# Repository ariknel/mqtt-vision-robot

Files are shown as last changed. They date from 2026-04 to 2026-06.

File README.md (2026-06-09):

# ESP32 MQTT Vision Robot

A line-following robot built around the **ESP32-DEVKITC V1**, featuring dual motor control via L298N, 3 IR line sensors, 3 ultrasonic distance sensors, and an LM2596S-ADJ buck converter powered by a custom 2S 18650 battery pack (8.4V fully charged). Fully controlled via a custom **Android MQTT app** with live telemetry, accelerometer tilt control, and WASD buttons.

All firmware is written in pure **ESP-IDF v5.x** (C). No Arduino framework. WiFi credentials are provisioned over BLE using NimBLE. Communication with the app uses MQTT over WiFi. The Android app runs an embedded MQTT broker — no cloud or external server needed.

---
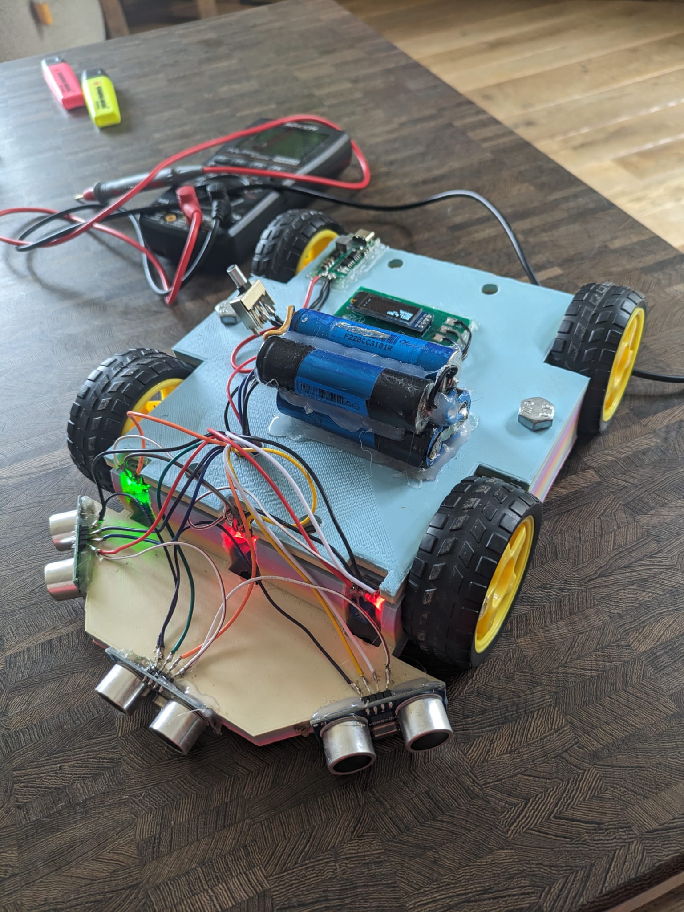
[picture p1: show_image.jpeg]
Show Image

## Table of Contents

- [Hardware Bill of Materials](#hardware-bill-of-materials)
- [Schematic](#schematic)
- [PCB Design Process](#pcb-design-process)
- [PCB Assembly & Testing](#pcb-assembly--testing)
- [Chassis — 3D Printed](#chassis--3d-printed)
- [Pinout Reference](#pinout-reference)
- [JST Connector Wiring](#jst-connector-wiring)
- [Power System](#power-system)
- [Motor Control](#motor-control)
- [Sensors](#sensors)
- [Firmware — Build & Flash](#firmware--build--flash)
- [Android App](#android-app)
- [First Run & WiFi Provisioning](#first-run--wifi-provisioning)
- [Control Modes](#control-modes)
- [Known Issues](#known-issues)
- [Build Log](#build-log)

---

## Hardware Bill of Materials

| Component | Part | Notes |
|---|---|---|
| MCU | ESP32-DEVKITC V1 | Dual-core, WiFi + Bluetooth |
| Motor Driver | L298N | Desoldered from L298N breakout module — correct Schottky freewheeling diodes reused |
| Buck Converter | LM2596S-ADJ | 8.4V → 5V, output set via RV1 trimpot. Rectifier diode: SS34 Schottky |
| Battery | Custom 2S 18650 pack (2× 18650 cells) | 8.4V fully charged, connected via JST J3 (2-pin) |
| Charger | Hailege 2S USB-C BMS Boost Charger | Charges to 8.4V via USB-C (5V input), overcharge and overcurrent protection |
| IR Sensors | Generic IR reflectance module × 3 | Digital output, 3.3V logic — connected via JST-B (10-pin) |
| Ultrasonic Sensors | HC-SR04 × 3 — **2021+ version** | ECHO outputs 3.3V logic — no voltage divider needed. Connected via JST-A (10-pin) |
| OLED Display | SSD1306 128×32 I2C | Mounted on a separate daughter PCB above the main board |
| Android App | Custom (Kotlin, Android Studio, API 29+) | Embedded MQTT broker + WASD / accelerometer control |

> The L298N was desoldered from a breakout module to reuse its Schottky freewheeling diodes, which are the correct type and are already soldered in the correct polarity.

> The HC-SR04 **must** be the 2021+ version, whose ECHO pin outputs 3.3V logic. Earlier versions output 5V on ECHO and require a voltage divider before connecting to ESP32 GPIO. Check the PCB revision marking or measure with a multimeter before connecting.

---

## Schematic

### Full Schematic — Rev 2

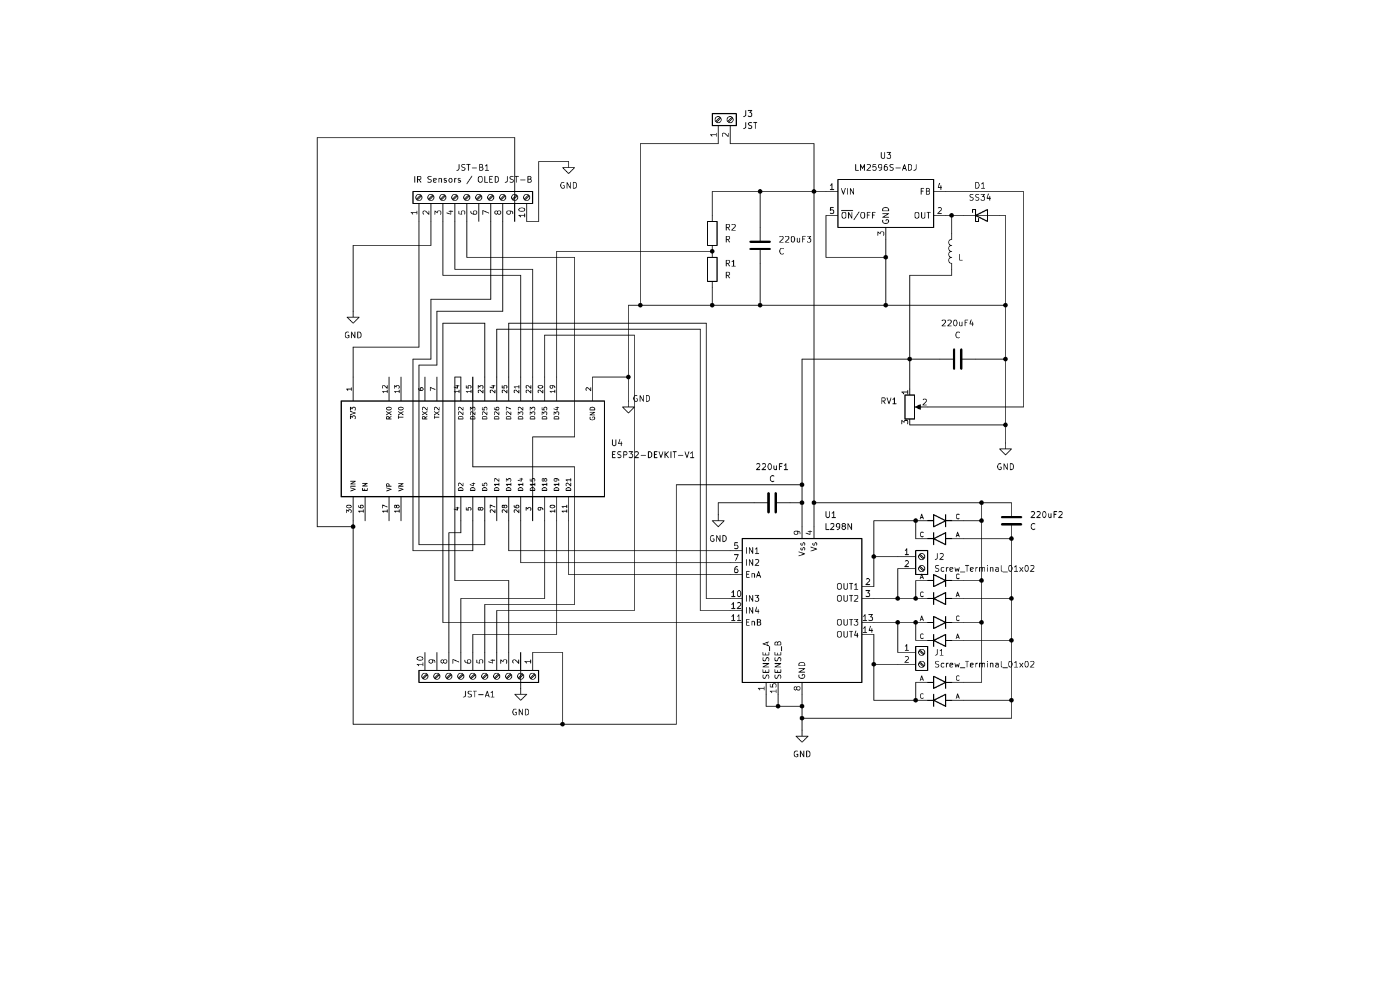
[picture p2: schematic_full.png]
Full Schematic


*ESP32-DEVKITC V1 + LM2596S-ADJ power section + L298N motor driver + JST-A ultrasonic connector + JST-B IR / OLED connector*

### LM2596S-ADJ — Buck Converter & Battery Monitor

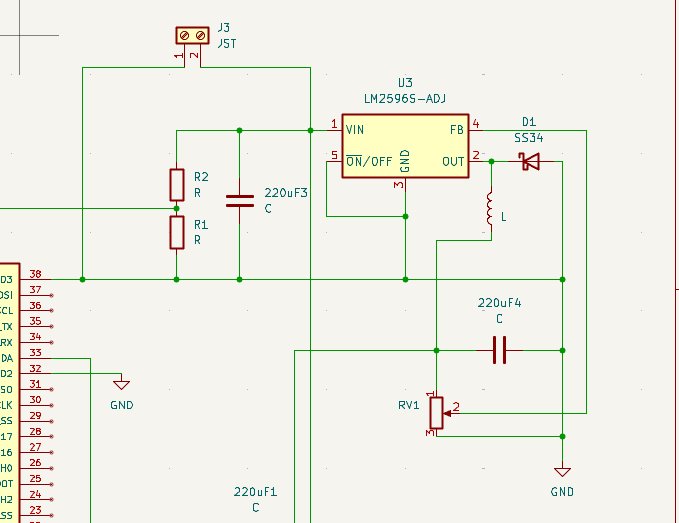
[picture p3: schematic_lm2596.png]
LM2596 Section


*8.4V input via J3 (2-pin JST). R1/R2 voltage divider (100 kΩ / 100 kΩ) feeds battery voltage to D34 for ADC monitoring. LM2596S-ADJ with SS34 Schottky diode D1, inductor L1, 220 µF input and output electrolytic capacitors, RV1 trimpot setting the 5V output via the FB pin.*

### L298N — Motor Driver

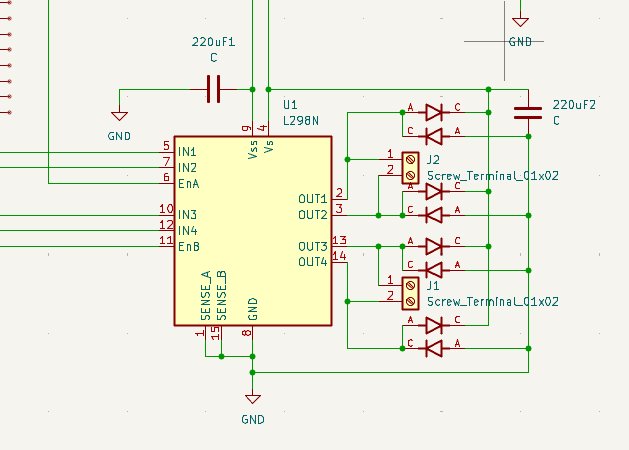
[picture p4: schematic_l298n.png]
L298N Section


*L298N dual H-bridge with 8 Schottky freewheeling diodes. Motor A: IN1 (D13), IN2 (D14), EnA (D21). Motor B: IN3 (D27), IN4 (D26), EnB (D25). Motor outputs routed to J1 and J2 screw terminals.*

---

## PCB Design Process

The PCB is designed in **KiCad**. Custom component footprints are in the `/footprints` folder of this repo.

### Step 1 — Schematic Capture

Built in KiCad's schematic editor. The following components were not in KiCad's default library and were imported manually:

- ESP32-DEVKITC V1
- LM2596S-ADJ
- L298N
- JST-A and JST-B connectors

### Step 2 — Component Placement

Components were placed manually, following these principles:

- **LM2596 power section** — tight left-to-right cluster: input capacitor → IC → inductor → Schottky diode → output capacitor. Keeps the switching current loop short to minimise EMI.
- **L298N** — centered on the board, freewheeling diodes grouped tightly around each output pair.
- **ESP32-DEVKITC V1** — centered, GPIO pins facing the connector side to reduce trace crossings.
- **JST-A and JST-B** — right edge of the board for clean external cable routing.
- **J1/J2 screw terminals** — bottom edge for easy motor wire access.
- **J3 power connector** — left edge, close to the LM2596 input.

### Step 3 — Design Rules

Configured via **File → Board Setup → Design Rules → Net Classes**:

| Netclass | Track Width | Clearance | Applied To |
|---|---|---|---|
| Default | 0.25 mm | 0.2 mm | All signal traces (GPIO, sensors, PWM) |
| Power | 1.0 mm | 0.8 mm | GND, 8.4V battery rail, 5V rail, motor output nets |

Power netclass assigned to: `GND`, `Net-(J3-Pin_2)` (8.4V battery), `Net-(JST-A1-Pin_1)` (5V rail), `Net-(J1-Pin_1/2)` (Motor A outputs), `Net-(J2-Pin_1/2)` (Motor B outputs).

### Step 4 — Board Outline

Rectangle drawn on the `Edge.Cuts` layer with ~5 mm clearance around all components using **Place → Rectangle**.

### Step 5 — Mounting Holes

4× `MountingHole_4.3x6.2mm_M4_Pad` placed at each corner for chassis standoff mounting. References set to H1–H4 (required for FreeRouter SES import compatibility).

### Step 6 — DRC (pre-routing)

Run via **Inspect → Design Rules Checker → Run DRC**:
- 3 silkscreen overlap warnings — fixed
- 0 footprint errors
- 69 unconnected pads (expected before routing)

### Step 7 — Auto-Routing with FreeRouter

1. **File → Export → Specctra DSN**
2. Open in FreeRouter, run the auto-router
3. **File → Import → Specctra Session (.ses)**
4. Review all traces manually and re-run DRC

Post-import DRC found 28 violations: decorative text placed on F.Cu (causing trace conflicts), IC pad spacing vs. power clearance rule violations, and 3 dangling track stubs. All fixed:
- Decorative text moved to F.Silkscreen layer
- Power clearance reduced from 0.8 mm to 0.5 mm to match IC footprint pad spacing
- 3 dangling stubs deleted

Final DRC: **0 errors, 2 warnings** (mounting hole library mismatch — ignorable).

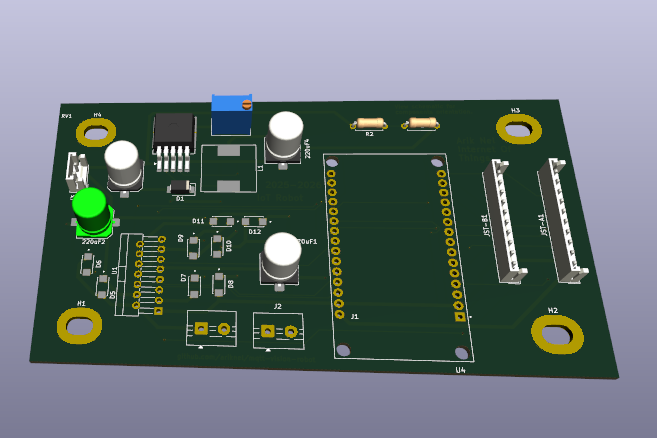
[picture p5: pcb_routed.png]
Routed PCB


*Fully routed 2-layer PCB. Red = F.Cu, blue = B.Cu. Thick traces = Power netclass (0.8 mm), thin = Default (0.25 mm).*

### Step 8 — Gerber Export & Manufacturing

> Board is production-ready. Final DRC: 0 errors.

1. **File → Plot** → Gerber format
2. Export all layers: F.Cu, B.Cu, F.Silkscreen, B.Silkscreen, F.Mask, B.Mask, Edge.Cuts + drill files
3. Submit to manufacturer — ordered as 2-layer, HASL finish, 5 copies

Gerber files are in the `/gerber` folder of this repo.

---

### OLED Display Board

A second small PCB was designed to mount a **SSD1306 128×32 I2C OLED** on top of the robot chassis. It sits above the main PCB, hides the main board from view, and connects back via the spare pins on JST-B.

The board contains no active components — just 4 solder test pads (H1–H4) for wire routing, a 4-pin JST connector (J5), and the OLED module footprint. Gerber files are in the `/gerber` folder alongside the main board gerbers.

**Why a separate board:**
- The main PCB had no remaining space for an OLED footprint
- Mounting on top of the chassis hides the main board for a cleaner look
- Can be detached and replaced independently from the main board

#### OLED Board Schematic

OLED Schematic

*J5 (4-pin JST) connects to H1 (GND), H2 (VCC), H3 (SCL), H4 (SDA). Short wires run from these pads to the OLED module pins.*

#### OLED Board PCB Layout

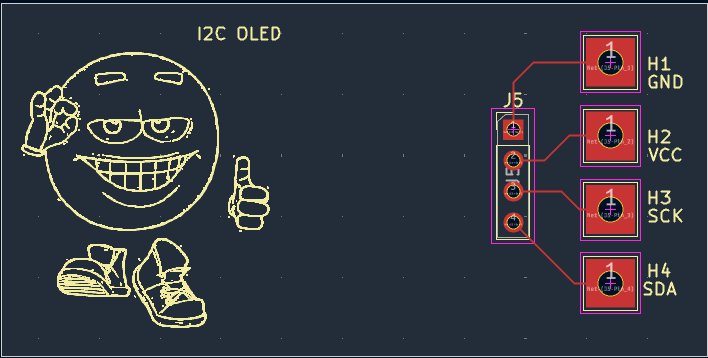
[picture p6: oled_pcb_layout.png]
OLED PCB Layout


*Minimal PCB — 4 test pad holes + JST connector. Sits on top of chassis above the main board.*

#### OLED Board 3D View

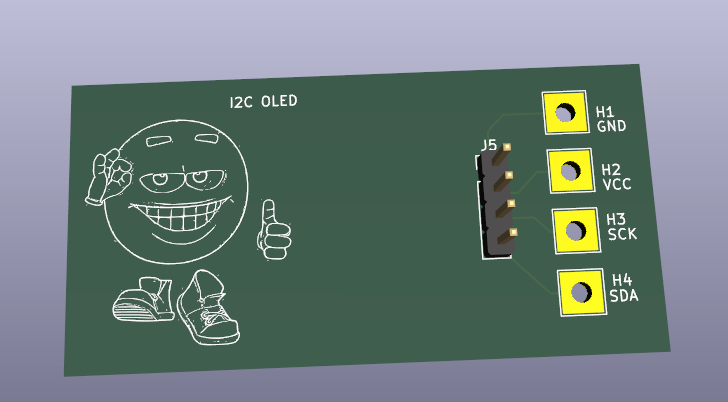
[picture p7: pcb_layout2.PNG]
OLED 3D View


#### OLED — JST-B Connection

The OLED board connects using the spare pins on JST-B (the IR sensor connector):

| JST-B Pin | Signal | OLED Board Pad | ESP32 GPIO |
|---|---|---|---|
| 6 | — spare — | — | — |
| 7 | SDA | H4 | D4 (Pin 5) |
| 8 | SCL | H3 | D5 (Pin 8) |
| 9 | VCC (5V) | H2 | — |
| 10 | GND | H1 | — |

> Verify your SSD1306 module accepts 5V on VCC. Most breakout modules have an onboard 3.3V LDO and accept 5V. Bare OLED modules without a regulator require 3.3V only.

> The ESP32's default I2C pins (D21/D22) are both used by the motor driver. I2C is remapped to D4 (SDA) and D5 (SCL) inside the ESP-IDF I2C driver configuration in `oled.c`.

#### OLED — What It Displays

| Line | Content |
|---|---|
| 1 | Battery voltage |
| 2 | MQTT connection status |
| 3 | Current mode (MANUAL / LINE FOLLOW) |
| 4 | Robot state (FOLLOWING / AVOIDING / RECOVERING) |

---

## PCB Assembly & Testing

**Do not solder all components at once.** Bring up the power circuit first and verify the output voltage before soldering the ESP32 or any sensors. This protects the ESP32 from overvoltage if the trimpot is set incorrectly from the factory.

### Step 1 — Inspect the Received PCBs

- Check for visible manufacturing defects: solder bridges, missing soldermask, lifted pads
- Hold the PCB up to light to check copper layer alignment
- Verify silkscreen labels match the schematic reference designators

### Step 2 — Solder the Buck Converter Circuit Only

Solder only the following components. Leave everything else unpopulated.

| Ref | Component |
|-----|---|
| J3 | 2-pin JST power input connector |
| U_LM2596 | LM2596S-ADJ IC |
| D1 | SS34 Schottky diode — stripe (band) = cathode |
| L1 | Inductor |
| C_in | 220 µF electrolytic input capacitor — stripe = GND (negative) |
| C_out | 220 µF electrolytic output capacitor — stripe = GND (negative) |
| RV1 | Trimpot |
| R1, R2 | 100 kΩ resistors (battery ADC voltage divider) |

Do **not** solder: ESP32, L298N, JST-A, JST-B, J1/J2 screw terminals, or any sensors yet.

### Step 3 — Set the Buck Converter Output to 5V
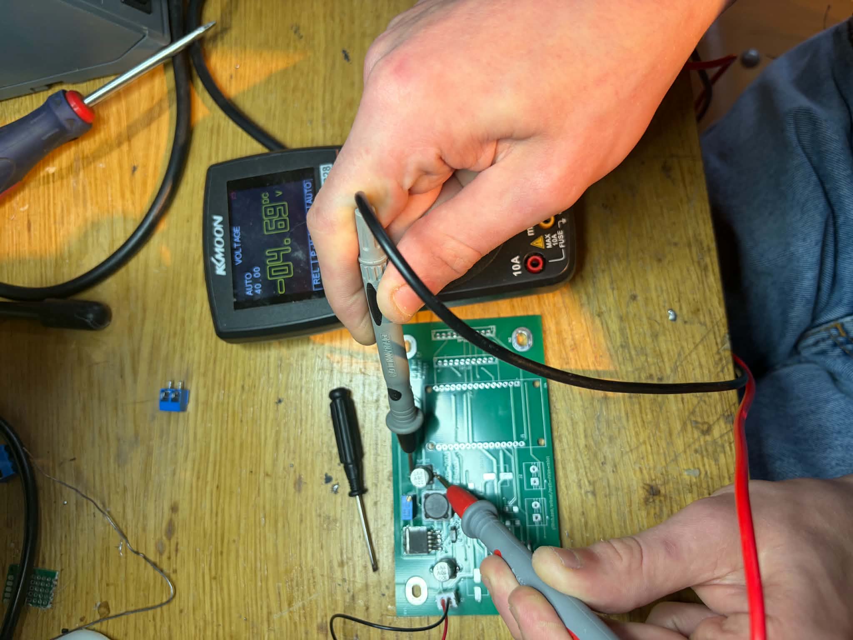
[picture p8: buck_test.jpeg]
Setting Buck to 5V

This is the most critical step. The LM2596S-ADJ output voltage is set by RV1. If left at the wrong position it may output the full battery voltage (up to 8.4V) to the 5V rail, which will destroy the ESP32.

1. Connect the 2S 18650 battery pack to J3 (Pin 1 = GND, Pin 2 = battery positive)
2. Set your multimeter to DC voltage
3. Place probes across the output capacitor C_out (or the 5V rail test points)
4. Slowly adjust RV1 until the meter reads **5.0V**
5. Confirm the reading is stable with no oscillation
6. Disconnect the battery

### Step 4 — Verify the Battery ADC Divider

> The firmware ADC saturates when the divider midpoint exceeds ~3.1V, which corresponds to a battery voltage of ~6.2V. This is a hardware limitation — the battery reading shows ~6.2V on a healthy 2S pack and only starts falling below 6.2V when the pack is nearly depleted. The app thresholds are set at 6.0V / 5.5V to account for this. This can be fixed in software with some calculations.

### Step 5 — Solder Remaining Components

Now that the 5V rail is confirmed correct and safe:

| Ref | Component |
|-----|---|
| U_L298N | L298N motor driver IC + all 8 Schottky freewheeling diodes |
| U_ESP32 | ESP32-DEVKITC V1 |
| JST-A | 10-pin connector (ultrasonic sensors) |
| JST-B | 10-pin connector (IR sensors + OLED) |
| J1, J2 | Screw terminals (motor A and motor B outputs) |

Solder the OLED daughter board separately — it is a standalone PCB.

### Step 6 — Power-On Verification

1. Connect the battery to J3
2. The ESP32 should boot — the onboard LED comes on
3. Connect the ESP32 to a PC via USB
4. Open a serial monitor at **115200 baud**
5. You should see BLE provisioning log output: `I (xxx) PROV: advertising as "IoT-Robot"`
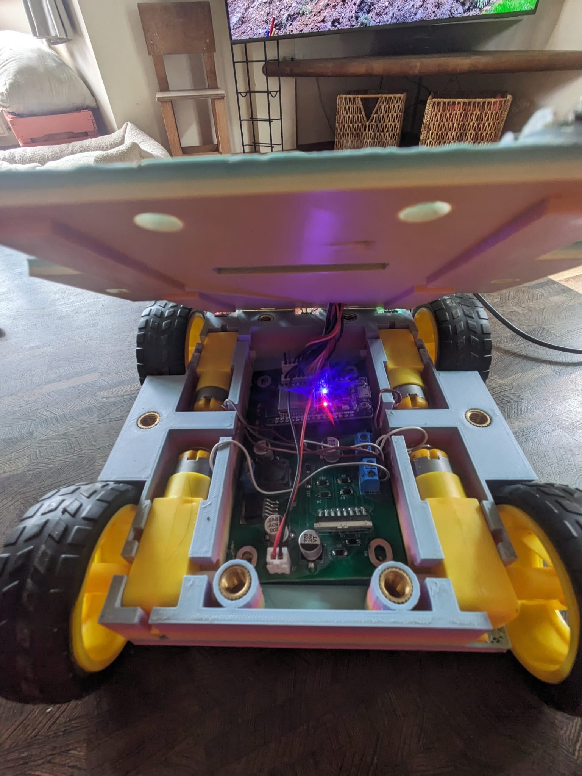
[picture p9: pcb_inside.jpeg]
PCB Mounted, still needs screwing down

If nothing appears on the serial monitor:
- Check battery polarity on J3
- Re-measure the 5V rail — must be 5V, not higher
- Verify ESP32 is seated correctly and all pins are soldered

### Step 7 — Connect and Test Sensors

Connect sensors one at a time and watch the serial output:

1. **IR sensors (JST-B)** — move a reflective object under each sensor; the digital output should toggle between 0 and 1
2. **Ultrasonic sensors (JST-A)** — wave your hand in front of each sensor; distances should appear in the telemetry log
3. **OLED board** — connect via JST-B spare pins 7–10; the display should show battery voltage and MQTT status after provisioning
4. **Motors (J1, J2)** — connect motors and verify direction in manual mode via the Android app

---

## Chassis — 3D Printed

The robot chassis is designed in **Autodesk Inventor** and 3D printed in PLA. The STEP file is in the root of this repo for reference and modification.

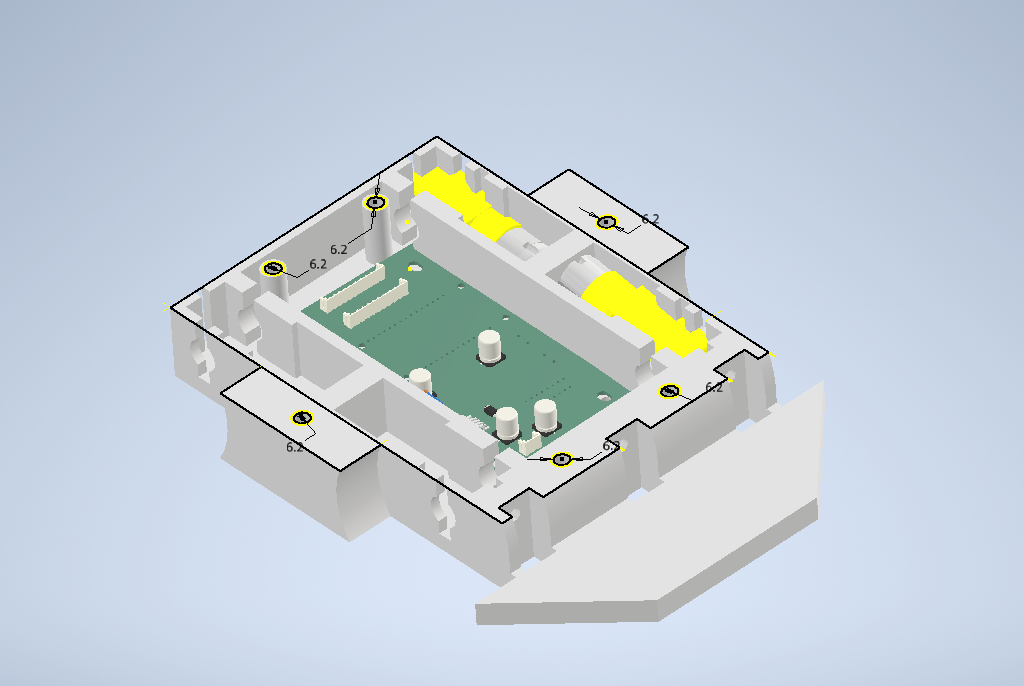
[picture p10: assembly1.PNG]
Chassis Assembly


*Autodesk Inventor assembly — PCB on standoffs, motor mounts, battery compartment, and sensor positions.*

**Design details:**
- IR sensors mount on the underside, facing down toward the ground for line detection
- HC-SR04 sensors mount on the front face in left, center, and right positions
- Motor mounts are integrated into the chassis base
- PCB sits on M4 standoffs matching the 4 corner mounting holes on the PCB
- Battery compartment is accessible from the bottom of the chassis

**Print settings used:** PLA, 0.2 mm layer height, 20% infill for non-structural sections, 50% infill for motor mounts and standoff pillars.

---

## Pinout Reference

### Motor Driver — L298N

| L298N Signal | ESP32 Label | ESP32 Pin | Type |
|---|---|---|---|
| IN1 | D13 | Pin 28 | Digital Output — Motor A direction |
| IN2 | D14 | Pin 26 | Digital Output — Motor A direction |
| EnA | D21 | Pin 11 | PWM Output — Motor A speed |
| IN3 | D27 | Pin 25 | Digital Output — Motor B direction |
| IN4 | D26 | Pin 24 | Digital Output — Motor B direction |
| EnB | D25 | Pin 23 | PWM Output — Motor B speed |

### Battery Monitor

| Function | ESP32 Label | ESP32 Pin | Notes |
|---|---|---|---|
| Battery ADC | D34 | Pin 19 | R1/R2 divider from J3 Pin 2. Input-only GPIO, ADC1 — WiFi safe |

### IR Line Sensors — JST-B (10-pin)

| Sensor | ESP32 Label | ESP32 Pin | Notes |
|---|---|---|---|
| IR Left | D32 | Pin 21 | ADC1 — WiFi/MQTT safe |
| IR Center | D33 | Pin 22 | ADC1 — WiFi/MQTT safe |
| IR Right | D15 | Pin 3 | Mild strapping pin — IR signal defaults LOW at boot, no conflict |

### Ultrasonic Sensors HC-SR04 (2021+) — JST-A (10-pin)

| Sensor | TRIG Label | TRIG Pin | ECHO Label | ECHO Pin | Notes |
|---|---|---|---|---|---|
| Left | D22 | Pin 14 | D35 | Pin 20 | ECHO input-only GPIO, ADC1 |
| Center | D23 | Pin 15 | D19 | Pin 10 | |
| Right | D18 | Pin 9 | D2 | Pin 4 | GPIO2 = onboard LED — LED flashes with echoes (cosmetic, sensor reads correctly) |

> HC-SR04 2021+: ECHO outputs 3.3V logic — direct connection to ESP32, no voltage divider needed.

### JST Power Connector — J3 (2-pin)

| Pin | Signal |
|-----|---|
| 1 | GND |
| 2 | Battery positive (8.4V fully charged) |

### Complete GPIO Map

| Label | ESP32 Pin | Function | Type |
|---|---|---|---|
| D2 | Pin 4 | ECHO Right (ultrasonic) | Input |
| D4 | Pin 5 | OLED SDA | I2C |
| D5 | Pin 8 | OLED SCL | I2C |
| D13 | Pin 28 | Motor A IN1 | Output |
| D14 | Pin 26 | Motor A IN2 | Output |
| D15 | Pin 3 | IR Right | Input |
| D18 | Pin 9 | TRIG Right (ultrasonic) | Output |
| D19 | Pin 10 | ECHO Center (ultrasonic) | Input |
| D21 | Pin 11 | EnA — Motor A speed | PWM Output |
| D22 | Pin 14 | TRIG Left (ultrasonic) | Output |
| D23 | Pin 15 | TRIG Center (ultrasonic) | Output |
| D25 | Pin 23 | EnB — Motor B speed | PWM Output |
| D26 | Pin 24 | Motor B IN4 | Output |
| D27 | Pin 25 | Motor B IN3 | Output |
| D32 | Pin 21 | IR Left | Input — ADC1 |
| D33 | Pin 22 | IR Center | Input — ADC1 |
| D34 | Pin 19 | Battery ADC | Input — ADC1, input-only GPIO |
| D35 | Pin 20 | ECHO Left (ultrasonic) | Input — ADC1, input-only GPIO |

---

## JST Connector Wiring

### JST-A — Ultrasonic Sensors (10-pin)

| Pin | Signal | ESP32 Label | ESP32 Pin |
|-----|---|---|---|
| 1 | 5V (shared VCC) | — | — |
| 2 | GND (shared) | — | GND |
| 3 | TRIG Left | D22 | Pin 14 |
| 4 | ECHO Left | D35 | Pin 20 |
| 5 | TRIG Center | D23 | Pin 15 |
| 6 | ECHO Center | D19 | Pin 10 |
| 7 | TRIG Right | D18 | Pin 9 |
| 8 | ECHO Right | D2 | Pin 4 |
| 9–10 | — spare — | — | — |

### JST-B — IR Line Sensors + OLED (10-pin)

| Pin | Signal | ESP32 Label | ESP32 Pin |
|-----|---|---|---|
| 1 | 3.3V (shared VCC) | — | — |
| 2 | GND (shared) | — | GND |
| 3 | IR Left | D32 | Pin 21 |
| 4 | IR Center | D33 | Pin 22 |
| 5 | IR Right | D15 | Pin 3 |
| 6 | — spare — | — | — |
| 7 | OLED SDA | D4 | Pin 5 |
| 8 | OLED SCL | D5 | Pin 8 |
| 9 | OLED VCC (5V) | — | — |
| 10 | OLED GND | — | GND |

VCC and GND are daisy-chained across all sensors within each connector group.

---

## Power System

```
[2S 18650 Battery Pack — 8.4V fully charged]
          │
       J3 (2-pin JST)  —  Pin 1: GND,  Pin 2: 8.4V
          │
          ├── R1 / R2 voltage divider (100 kΩ / 100 kΩ) ──── D34 Pin 19 (battery ADC)
          ├── 220 µF bulk input capacitor
          ├── L298N VS pin  (motors run from raw battery voltage)
          │
       LM2596S-ADJ  (D1: SS34 Schottky, RV1 trimpot → FB → 5V out)
       Output: 220 µF capacitor
          │
         5V rail ─────────── HC-SR04 VCC (JST-A Pin 1)
          │                  OLED VCC (JST-B Pin 9)
          │
       ESP32-DEV VIN ──── onboard LDO ──── 3.3V rail ──── IR sensor VCC (JST-B Pin 1)
```

The motors are powered directly from the battery voltage through the L298N VS pin — they operate at the full battery voltage, not the regulated 5V. The 5V rail powers only the ultrasonic sensors and OLED. The ESP32's onboard LDO produces the 3.3V rail for IR sensors and internal logic.

---

## Motor Control

The robot uses differential drive with the L298N dual H-bridge. Speed is controlled by PWM on the Enable pins (EnA/EnB). Direction is set by the IN1–IN4 logic inputs.

### H-Bridge Truth Table (per channel)

| IN_A | IN_B | Result |
|---|---|---|
| HIGH | LOW | Forward |
| LOW | HIGH | Reverse |
| LOW | LOW | Coast (free spin) |
| HIGH | HIGH | Brake |

### Differential Steering

| Action | Motor A (Left) | Motor B (Right) |
|---|---|---|
| Forward | Full speed | Full speed |
| Turn Left | Reduced speed | Full speed |
| Turn Right | Full speed | Reduced speed |
| Hard Left | Stop | Full speed |
| Hard Right | Full speed | Stop |
| Reverse | Full back | Full back |
| Spin Left | Full back | Full forward |
| Spin Right | Full forward | Full back |

> **Hardware note:** Motor A (left) has IN1 and IN2 wired backwards on the PCB. This is corrected in firmware inside the `drive()` function by inverting the polarity sent to PIN_IN1/PIN_IN2 for Motor A only. All higher-level motor commands (forward, reverse, turn, spin) are unaffected.

---

## Sensors

### IR Line Sensors (×3)

3 IR reflectance sensors mounted under the chassis for line detection. Digital output, 3.3V modules, connected via JST-B.

- All three GPIOs are on ADC1 — WiFi and MQTT remain active while reading
- No level shifting required (sensors output 3.3V logic)
- Firmware applies a 2-consecutive-read debounce before accepting a new state

**MQTT telemetry topic:** `robot/telemetry/ir`
```json
{"left": 0, "center": 1, "right": 0}
```

`1` = line detected (dark surface), `0` = no line (bright surface).

### Ultrasonic Sensors HC-SR04 2021+ (×3)

3 ultrasonic distance sensors for obstacle detection (left, center, right), connected via JST-A. Powered from the 5V rail.

ECHO connects directly to ESP32 GPIO — no voltage divider required (2021+ version outputs 3.3V logic).

Distance measurement uses an **interrupt-driven ISR** (`GPIO_INTR_ANYEDGE`). The rising edge records a timestamp in µs; the falling edge computes the distance as `pulse_us / 58`. This replaces the earlier polling approach, which missed short echo pulses at distances under ~170 cm.

**MQTT telemetry topic:** `robot/telemetry/ultrasonic`
```json
{"left": 24, "center": 8, "right": 31}
```

Values are in centimetres.

---

## Firmware — Build & Flash

The firmware is written in **C using ESP-IDF v5.4.1**. No Arduino framework, no PlatformIO.

### Project Structure

```
firmware/
├── CMakeLists.txt          — project root (IDF project)
├── sdkconfig.defaults      — NimBLE enabled, 8 KB main stack
└── main/
    ├── CMakeLists.txt      — lists all source files and dependencies
    ├── main.c              — app_main + 10 ms main loop
    ├── config.h            — all pin definitions and constants
    ├── provisioning.c/h    — BLE credential provisioning (NimBLE + NVS)
    ├── sensors.c/h         — IR, ultrasonic (ISR-driven), battery ADC
    ├── state_machine.c/h   — autonomy logic + motor control
    ├── mqtt.c/h            — WiFi STA + esp-mqtt client (event-driven)
    └── oled.c/h            — SSD1306 raw I2C driver + 5×7 font (no external lib)
```

### Firmware Architecture

```
app_main
  ├── provisioning_init()   — blocks on first boot (BLE); loads NVS on subsequent boots
  ├── sensors_init()        — configures GPIO, ISR handlers, ADC
  ├── state_machine_init()  — initialises LEDC channels and motor GPIOs
  ├── mqtt_init()           — blocks until WiFi + MQTT connected
  └── oled_init()           — I2C probe, skip gracefully if no OLED

Main loop (10 ms period)
  ├── sensors_read_ir()
  ├── sensors_read_ultrasonic()
  ├── sensors_read_battery()
  ├── state_machine_update()
  ├── every 100 ms → mqtt_publish_telemetry()
  └── every 500 ms → oled_update()
```

### Building on Windows (Docker + WSL2)

Build runs inside a Docker Dev Container. Flashing runs via WSL2 Ubuntu.

**One-time setup:**

1. Install [Docker Desktop](https://www.docker.com/products/docker-desktop)
2. Install WSL2 Ubuntu — PowerShell as Administrator:
   ```
   wsl --install -d Ubuntu
   ```
3. Install usbipd — PowerShell as Administrator:
   ```
   winget install usbipd
   ```
4. Inside Ubuntu terminal, install esptool:
   ```bash
   sudo apt update && sudo apt install pipx -y
   pipx install esptool
   pipx ensurepath
   source ~/.bashrc
   ```
5. Add yourself to the dialout group (then close and reopen the Ubuntu terminal):
   ```bash
   sudo usermod -aG dialout $USER
   ```

**Build (each session):**

1. Make sure Docker Desktop is running
2. Open the `mqttvision` folder in VS Code
3. `Ctrl+Shift+P` → **Dev Containers: Reopen in Container**
4. In the integrated terminal:
   ```bash
   cd /project/firmware
   idf.py build
   ```

**Flash (each session):**

1. Attach the ESP32 to WSL2 — PowerShell as Administrator:
   ```
   usbipd list
   usbipd bind --busid <BUSID>
   usbipd attach --wsl --busid <BUSID>
   ```
   The BUSID is listed next to "Silicon Labs CP210x" or "CH340". It may change if you use a different USB port.

2. Fix USB permissions if needed — Ubuntu terminal:
   ```bash
   sudo chmod 666 /dev/ttyUSB0
   ```

3. Flash — Ubuntu terminal:
   ```bash
   cd /mnt/c/Users/<you>/Desktop/mqttvision/firmware/build
   esptool.py --chip esp32 -p /dev/ttyUSB0 -b 460800 --before default_reset --after hard_reset write_flash @flash_args
   ```

4. Open the serial monitor:
   ```bash
   screen /dev/ttyUSB0 115200
   ```
   Exit with `Ctrl+A` then `K`.

**Erase flash** (when NVS needs clearing — e.g. stale WiFi credentials):
```bash
esptool.py --chip esp32 -p /dev/ttyUSB0 erase_flash
```
Then re-flash using Step 3 above.

### Building on Linux (Arch / Ubuntu native)

**One-time setup (Arch):**
```bash
sudo pacman -S git cmake ninja python python-pip python-pipx
sudo usermod -aG uucp $USER        # log out and back in after this
git clone --recursive https://github.com/espressif/esp-idf.git ~/esp/idf
cd ~/esp/idf && git checkout v5.4.1 && ./install.sh esp32
echo 'source ~/esp/idf/export.sh' >> ~/.bashrc && source ~/.bashrc
idf.py --version                   # should show ESP-IDF v5.4.1
```

**Build and flash:**
```bash
cd path/to/mqttvision/firmware
idf.py build
idf.py -p /dev/ttyUSB0 flash monitor
```

If permission is denied on `/dev/ttyUSB0`: `sudo chmod 666 /dev/ttyUSB0` (permanent: `sudo usermod -aG uucp $USER` then log out/in).

### Key Constants (config.h)

```c
/* Motor pins — L298N */
#define PIN_IN1   13    /* Motor A direction (wired backwards on PCB — corrected in drive()) */
#define PIN_IN2   14
#define PIN_ENA   21    /* Motor A speed (PWM) */
#define PIN_IN3   27    /* Motor B direction */
#define PIN_IN4   26
#define PIN_ENB   25    /* Motor B speed (PWM) */

/* IR sensors */
#define PIN_IR_LEFT    32
#define PIN_IR_CENTER  33
#define PIN_IR_RIGHT   15
#define IR_LINE_VALUE   0    /* GPIO level when sensor is on a dark line */
#define IR_DEBOUNCE_READS  2

/* Ultrasonic sensors */
#define PIN_TRIG_LEFT    22
#define PIN_ECHO_LEFT    35
#define PIN_TRIG_CENTER  23
#define PIN_ECHO_CENTER  19
#define PIN_TRIG_RIGHT   18
#define PIN_ECHO_RIGHT    2  /* GPIO2 = onboard LED — flashes with echoes (cosmetic only) */
#define ULTRA_TIMEOUT_US  25000  /* ~4 m max range, abort echo wait after this */

/* OLED I2C */
#define PIN_OLED_SDA   4
#define PIN_OLED_SCL   5
#define OLED_ADDRESS   0x3C

/* Battery ADC — GPIO34, ADC1_CH6 */
#define PIN_BATTERY      34
#define BATTERY_R1       100000.0f
#define BATTERY_R2       100000.0f

/* Speed — 8-bit PWM duty (0–255) */
#define SPEED_BASE        150   /* default speed, overridden by app slider */
#define SPEED_AVOID        90   /* cautious obstacle avoidance speed */
#define SPEED_CORRECTION   75   /* gentle correction turn speed */
#define SPEED_POST_CORR    80   /* forward speed when re-acquiring line */
#define SPEED_RAMP_STEP     2   /* PWM duty added per 10 ms tick while on-line */

/* Obstacle thresholds (cm) */
#define OBSTACLE_WARN_CM  20
#define OBSTACLE_STOP_CM  12

/* State machine timing */
#define RECOVERY_SWEEP_MS    2000
#define RECOVERY_SPIN_MS     5000
#define AVOID_MIN_MS          500
#define POST_AVOID_FWD_MS     600
#define RECOVERY_CREEP_MS     150

/* Loop intervals */
#define TELEMETRY_INTERVAL_MS  100
#define OLED_UPDATE_MS         500
#define MAIN_LOOP_MS            10

/* BLE provisioning window on every boot */
#define BLE_PROV_WINDOW_MS  30000
```

### Autonomous Mode — State Machine

The firmware runs a 3-state machine when in autonomous (line-follow) mode:

```
         ┌──────────────┐
    ┌───▶│  FOLLOWING   │◀────────────┐
    │    └──────┬───────┘             │
    │           │ obstacle < 20 cm    │ line found
    │           ▼                     │
    │    ┌──────────────┐             │
    │    │   AVOIDING   │             │
    │    └──────┬───────┘             │
    │           │ line lost (0,0,0)   │ line found
    │           ▼                     │
    │    ┌──────────────┐             │
    └────│  RECOVERING  │─────────────┘
         └──────────────┘
               │ no line after 5 s
               ▼
            STOP — await manual override via MQTT
```

**FOLLOWING** — normal line tracking using the IR truth table below. In the table, `1` = line detected (sensor on dark surface), `0` = not on line.

| IR Left | IR Center | IR Right | Action |
|---|---|---|---|
| 0 | 1 | 0 | Forward — centered on line |
| 0 | 1 | 1 | Curve right gently |
| 1 | 1 | 0 | Curve left gently |
| 0 | 0 | 1 | Turn right hard |
| 1 | 0 | 0 | Turn left hard |
| 1 | 1 | 1 | All sensors on line — forward |
| 1 | 0 | 1 | Junction or crossing — continue forward |
| 0 | 0 | 0 | Line lost — enter RECOVERING |

**AVOIDING** — triggered when any ultrasonic sensor reads < 20 cm. Robot curves around the obstacle using the left/right distance comparison to choose which side to go, keeping the outer IR sensor tracking the line edge for as long as possible.

**RECOVERING** — all IR sensors show 0 (line lost):
1. Remember which side sensor was last active
2. Slow down, turn that direction for up to 2 s
3. If line is found → return to FOLLOWING
4. If not found after 2 s → slow 360° spin scan
5. If still not found → stop and wait for manual override via MQTT

In **manual mode**, the state machine is bypassed entirely. MQTT move commands drive the motors directly.

---

## Android App

The Android app is built in **Kotlin** with **Jetpack Compose** (no XML layouts), targeting **API 29 (Android 10+)**. It embeds a full MQTT broker — no external server or cloud service needed.

### Architecture

```
[Android Phone]
      │
      ├── Moquette MQTT Broker (foreground service, port 1883)
      │         │
      │         └── Eclipse Paho MQTT Client (subscribes + publishes)
      │
      │   Local WiFi Network
      │
[ESP32-DEVKITC V1]
      │
      └── esp-mqtt client (connects to phone IP:1883)
            ├── Subscribes: robot/control/move, mode, speed
            └── Publishes:  robot/telemetry/#
```

The phone's local WiFi IP address acts as the broker address. The ESP32 learns this IP during BLE provisioning and connects on port 1883.

**Connection sequence:**
1. App launches → Moquette broker starts as a foreground service on port 1883
2. `MainActivity` waits for `MqttBrokerService.isRunning`, then Paho connects to `localhost:1883`
3. ESP32 boots → 30-second BLE window expires → WiFi connects → esp-mqtt connects to phone IP:1883
4. Handshake complete — telemetry flows in, controls work

### File Structure

```
MqttVisionRobot/app/src/main/java/com/ariknel/mqttvisionrobot/
├── MainActivity.kt           — entry point, broker lifecycle, screen routing
├── MqttBrokerService.kt      — Moquette broker as Android foreground service
├── MqttClientManager.kt      — Eclipse Paho client, publish helpers
├── BleProvisioningManager.kt — BLE scan, connect, write credentials, receive reply
├── RobotState.kt             — global Compose state (telemetry, connection, mode)
├── TelemetryParser.kt        — parses robot/telemetry/# JSON into RobotState
├── RobotControlScreen.kt     — main control UI (StatusBar, D-pad, speed, tilt, telemetry)
└── ProvisioningScreen.kt     — BLE provisioning form (auto-detects broker IP)
```

### MQTT Topics

| Topic | Direction | Payload |
|---|---|---|
| `robot/control/move` | App → ESP32 | `forward` / `back` / `left` / `right` / `stop` |
| `robot/control/speed` | App → ESP32 | PWM value `0`–`255` |
| `robot/control/mode` | App → ESP32 | `manual` or `line_follow` |
| `robot/telemetry/ir` | ESP32 → App | `{"left":0,"center":1,"right":0}` |
| `robot/telemetry/ultrasonic` | ESP32 → App | `{"left":24,"center":8,"right":31}` |
| `robot/telemetry/battery` | ESP32 → App | `8.21` (float string, volts) |
| `robot/telemetry/speed` | ESP32 → App | `{"a":180,"b":180}` |

All messages use **QoS 0** (fire-and-forget). At a 100 ms telemetry rate, a missed packet is irrelevant.

### Telemetry Dashboard

| Widget | Source | Notes |
|---|---|---|
| IR indicators | `robot/telemetry/ir` | 3 dot indicators — filled = line detected |
| Ultrasonic distances | `robot/telemetry/ultrasonic` | Live cm readouts Left / Center / Right |
| Battery voltage | `robot/telemetry/battery` | Colour-coded: green / amber / red |
| BROKER status | Internal | Live dot — Moquette running on phone |
| MQTT status | Internal | Live dot — ESP32 connected to broker |

### App UI

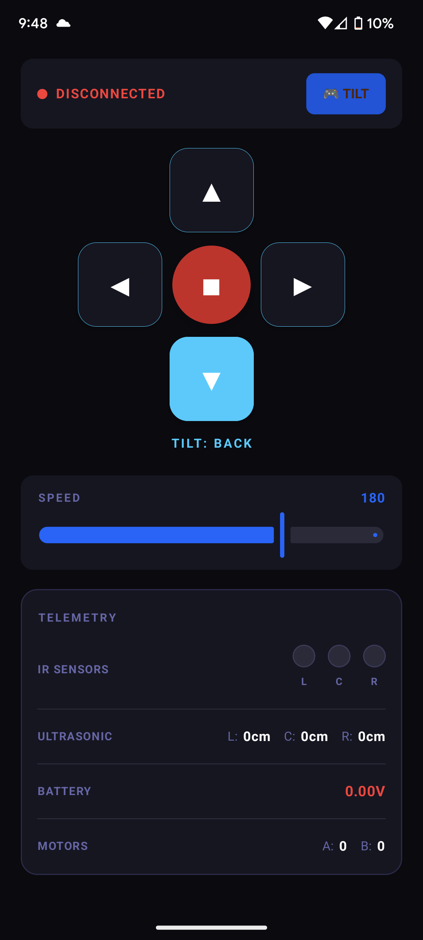
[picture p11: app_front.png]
App UI


### Dependencies

```kotlin
// MQTT Broker — Moquette embedded
implementation("io.moquette:moquette-broker:0.17")

// MQTT Client — Eclipse Paho
implementation("org.eclipse.paho:org.eclipse.paho.client.mqttv3:1.2.5")
implementation("org.eclipse.paho:org.eclipse.paho.android.service:1.1.1")

// Coroutines — async broker startup
implementation("org.jetbrains.kotlinx:kotlinx-coroutines-android:1.7.3")
```

---

## First Run & WiFi Provisioning

WiFi credentials and the MQTT broker IP are not hardcoded in firmware. On first boot, the ESP32 advertises over BLE and waits for provisioning.

**BLE service details:**

```
Device name:    IoT-Robot
Service UUID:   4fafc201-1fb5-459e-8fcc-c5c9c331914b
Characteristic: beb5483e-36e1-4688-b7f5-ea07361b26a8  (WRITE + NOTIFY)

Write payload:  {"ssid":"YourWiFi","password":"YourPass","broker":"192.168.x.x"}
Reply (notify): "OK"  — credentials saved, ESP32 restarts into WiFi mode
                "ERR" — malformed JSON, try again
```

**Boot behaviour:**

| Condition | What happens |
|---|---|
| No credentials in NVS (first boot) | BLE advertises indefinitely until credentials are received |
| Credentials present, normal boot | BLE advertises for 30 s (re-provision window), then stops and connects to WiFi |
| Boot immediately after provisioning | BLE skipped entirely (`fresh` NVS flag set), goes straight to WiFi |

**Provisioning steps:**

1. Power on the robot — the ESP32 advertises as `IoT-Robot`
2. Open the Android app and tap **BLE PROVISIONING**
3. The app auto-detects the broker IP from the phone's WiFi interface — only the WiFi SSID and password need to be typed in manually
4. Tap **PROVISION** — the app writes the JSON credentials over BLE
5. The ESP32 replies with "OK" and restarts
6. After restarting, the ESP32 connects to WiFi then to the MQTT broker running on the phone
7. The app status bar shows **BROKER OK** and **MQTT** connected

**Re-provisioning:** Power on the robot and connect via BLE within 30 seconds of boot.

**Full reset:** Erase NVS to force a first-boot state:
```bash
esptool.py --chip esp32 -p /dev/ttyUSB0 erase_flash
```
Then reflash the firmware.

---

## Control Modes

The app has two independent mode axes that can be combined freely.

### Drive Source — WASD or Tilt

Toggled by the **TILT/WASD** button. The accelerometer listener is registered and unregistered on each toggle to preserve battery.

**WASD mode (default):**

```
      [ W ]
 [ A ][ S ][ D ]
      [STP]
```

Hold a button to move; releasing it sends `stop`. The speed slider sets the PWM value (0–255).

**Tilt mode (accelerometer):**

| Tilt direction | Action |
|---|---|
| Forward | Move forward |
| Backward | Reverse |
| Left | Steer left |
| Right | Steer right |
| Flat | Stop |

Tilt speed is dynamic — a linear ramp from 80 to 255 as tilt angle increases. The speed slider updates in real time.

| Axis | Trigger threshold |
|---|---|
| Forward | `sensitivity − 0.6` (triggers slightly earlier for natural feel) |
| Left / Right | `sensitivity` |
| Reverse | `sensitivity + reverseGuard` |

A collapsible sensitivity panel (visible in tilt mode only) exposes two sliders:

| Slider | Effect |
|---|---|
| SENSITIVITY | Controls the trigger threshold for all axes |
| REVERSE GUARD | Extra tilt required to trigger reverse. Set to maximum (10) to disable reverse entirely |

### Autonomy — AUTO/MAN

Toggled by the **AUTO/MAN** button in the status bar.

- **MAN** — manual control via WASD or tilt. App publishes `manual` to `robot/control/mode`.
- **AUTO** — autonomous line-follow mode. App publishes `line_follow` to `robot/control/mode`. The control pad shows an "AUTO MODE" overlay and ignores all touch input. The ESP32 runs its state machine. The speed slider remains active — the firmware applies the current MQTT speed value in autonomous mode as well.

---

## Known Issues

| Priority | Issue | Status |
|---|---|---|
| Critical | LM2596 trimpot-only FB risk — if the RV1 wiper fails open, the full battery voltage reaches the 5V rail and destroys the ESP32. Fix: add R_upper 1 kΩ (VOUT→FB) + R_lower 1 kΩ (FB→GND) with RV1 in series with R_lower as a failsafe floor | Next PCB revision |
| Warning | Low-ESR capacitor recommended on LM2596 220 µF output capacitor | To verify |
| Info | ECHO Right on GPIO2 — the onboard LED flashes in sync with right ultrasonic echoes. GPIO2 cannot be changed without a PCB revision. The sensor reads correctly; the flashing is cosmetic only. | Accepted |
| OK | L298N Schottky freewheeling diodes — repurposed from module, correct type and polarity | Done |
| OK | LM2596 D1 = SS34 Schottky | Done |
| OK | HC-SR04 2021+ — ECHO direct to ESP32 GPIO, no voltage divider | Done |
| OK | All IR GPIOs on ADC1 — WiFi and MQTT remain active during sensor reads | Done |
| OK | No strapping pin conflicts in final pinout | Done |
| OK | D34 battery ADC — ADC1, input-only GPIO, WiFi safe | Done |
| OK | J3: Pin 1 = GND, Pin 2 = battery positive (8.4V) | Done |
| OK | ESP32-DEVKITC V1 has onboard 100 nF decoupling — no external cap needed | Done |
| OK | GPIO36/GPIO39 do not exist on DEVKITC V1 — replaced with D19 and D2 | Done |
| OK | BLE invisible after first provisioning — fixed with 30 s re-provision window + `fresh` NVS flag | Done |
| OK | BLE and WiFi radio conflict — NimBLE kept alive and competed with WiFi — fixed with `stop_nimble()` clean handoff before WiFi init | Done |
| OK | OLED I2C blocking serial (720 ms/update) when no OLED connected — fixed with `i2c_master_probe()` presence check at init | Done |
| OK | Android broker IP returning cellular IP on dual-SIM phones — fixed by filtering `allNetworks` for WiFi transport only | Done |
| OK | Moquette failing silently (`catch Exception` missed Netty errors) — fixed with `catch Throwable` + `data_path = filesDir.absolutePath` | Done |
| OK | ESP32 ignoring the speed slider — added `robot/control/speed` subscription + `state_machine_set_speed()` | Done |
| OK | Motor A (left) IN1/IN2 wired backwards on PCB — corrected in `drive()` by inverting PIN_IN1/PIN_IN2 polarity for Motor A only | Done |
| OK | WASD fast-tap locks direction (`collectIsPressedAsState` missed short presses) — replaced with `pointerInput` + `awaitEachGesture` / `awaitFirstDown` / `waitForUpOrCancellation` | Done |
| OK | No AUTO/MAN mode toggle in app — AUTO/MAN button added to StatusBar; sends `line_follow` / `manual` to `robot/control/mode` | Done |
| OK | Autonomous speed ignored MQTT speed commands — all `m_*` motor helpers now scale from `s_speed` instead of hardcoded constants | Done |
| OK | Battery reading ~13V (wrong VREF, no calibration) — replaced with `adc_cali_line_fitting` + 8-sample averaging; fallback uses correct 3100 mV full-scale | Done |
| Warning | Battery divider 2×100 kΩ (1:1) saturates ADC above ~6.2V — a healthy 2S pack reads fixed at ~6.2V; only drops below when the pack is nearly dead. App thresholds set to 6.0V / 5.5V. | Hardware limitation — acceptable |
| OK | OLED I2C timeouts at 400 kHz — SCL reduced to 100 kHz, timeout extended to 50 ms; error counter: bus reset on 5th consecutive fail, auto-disable on 20th | Done |
| OK | Ultrasonic always reading 400 cm (polling loop missed short echo pulses < ~170 cm) — replaced with interrupt-driven ISR (`GPIO_INTR_ANYEDGE`) recording µs-precision timestamps | Done |

---

## Build Log

| Date | Entry |
|---|---|
| 24 Apr 2026 | Rev 1 schematic complete. ESP32 + LM2596S-ADJ + L298N architecture established. |
| 24 Apr 2026 | EnA strapping conflict on D12 found and corrected → D21. |
| 24 Apr 2026 | R1/R2 confirmed as battery ADC voltage divider, not LM2596 feedback resistors. |
| 24 Apr 2026 | L298N repurposed from breakout module — correct Schottky freewheeling diodes confirmed. |
| 24 Apr 2026 | Android MQTT app architecture defined — embedded broker, dual control modes, telemetry dashboard. |
| 25 Apr 2026 | JST-A (ultrasonic) and JST-B (IR) connectors added to schematic and PCB. |
| 25 Apr 2026 | Full GPIO conflict check — all pins verified clean. |
| 25 Apr 2026 | HC-SR04 confirmed 2021+ version — voltage dividers removed from design. |
| 25 Apr 2026 | Final GPIO assignments locked in. LM2596 D1 = SS34 Schottky confirmed. |
| 25 Apr 2026 | Schematic Rev 2 exported — JST-A and JST-B fully connected. |
| 27 Apr 2026 | PCB design completed. L298N diode orientation corrected — all 8 diodes consistent anode/cathode orientation. |
| 27 Apr 2026 | Incorrect ESP32 footprint (WROOM-32D) found and replaced → ESP32-DEV DEVKITC V1. Custom footprints uploaded to `/footprints`. |
| 27 Apr 2026 | All pin numbers updated to DEVKITC V1 layout. GPIO36/39 replaced with D19/D2. 16 GPIOs used, 0 conflicts, 9 spare. |
| 27 Apr 2026 | DRC run — 3 silkscreen warnings fixed. 0 footprint errors. |
| 27 Apr 2026 | JST connector found placed upside down — fixed by flipping in KiCad PCB editor. |
| 27 Apr 2026 | Mounting hole references changed from numeric (1,2,3,4) to H1–H4 to resolve FreeRouter SES import error. |
| 27 Apr 2026 | FreeRouter auto-routing completed with 0 unrouted connections. Power netclass: 0.8 mm trace, 0.7 mm clearance. Signal: 0.25 mm trace, 0.2 mm clearance. |
| 27 Apr 2026 | SES imported into KiCad. All 28 DRC violations fixed: decorative text moved to F.Silkscreen, power clearance reduced to 0.5 mm to match IC pad spacing, 3 dangling stubs deleted. |
| 27 Apr 2026 | PCB routing complete. Final DRC: 0 errors, 2 warnings (mounting hole library mismatch — ignorable). Board is production-ready. |
| 27 Apr 2026 | GitHub URL added to PCB silkscreen. Gerber files exported and uploaded to `/gerber`. |
| 27 Apr 2026 | Power source confirmed: custom 2S 18650 pack (8.4V fully charged), charged via Hailege 2S USB-C BMS boost charger. |
| 27 Apr 2026 | Android app built and running. WASD + tilt mode, telemetry panel, speed slider. Dynamic tilt speed ramp, reverse guard, collapsible sensitivity panel added. |
| 27 Apr 2026 | Chassis design started in Autodesk Inventor. STEP file uploaded to repo. |
| 29 Apr 2026 | OLED board designed in KiCad — 128×32 SSD1306 I2C, separate PCB for mounting on chassis top. Connects via JST-B spare pins 7–10. ECHO Right moved D4 → D2; D4 and D5 assigned to OLED SDA/SCL. Gerbers added. |
| 29 Apr 2026 | Chassis assembly rendered in Autodesk Inventor. Assembly image added to repo. |
| 30 Apr 2026 | Final gerber review — main PCB and OLED board gerbers cross-checked. All layers verified (F.Cu, B.Cu, F.Silkscreen, B.Silkscreen, F.Mask, B.Mask, Edge.Cuts, drill). |
| 2 May 2026 | Main PCB and OLED board ordered from JLCPCB. 2-layer, HASL finish, 5 copies each. |
| 3 May 2026 | Firmware development started. All module headers defined: provisioning, sensors, state_machine, mqtt, oled. |
| 4 May 2026 | Chassis design finalised — mounting hole positions and motor mount spacing verified. |
| 4 May 2026 | sensors.c: IR reading with 2-read debounce, round-robin ultrasonic (non-blocking), battery ADC with voltage divider formula. state_machine.c skeleton. |
| 6 May 2026 | state_machine.c — 3-state machine (FOLLOWING / AVOIDING / RECOVERING) implemented. mqtt.c — WiFi connect, esp-mqtt event-driven client, telemetry JSON at 100 ms. |
| 7 May 2026 | provisioning.c — NimBLE GATT service, JSON credentials written to NVS. oled.c — SSD1306 raw driver, 5×7 font, battery + MQTT + mode/state display. |
| 8 May 2026 | main.c complete — all modules wired together and compiling. Chassis sent to 3D printer (PLA, 0.2 mm layer height, 20 % / 50 % infill). |
| 10 May 2026 | CLAUDE.md created. README audited and updated: OLED features, BLE provisioning section, constants. |
| 10 May 2026 | Auto-changelog hook configured in Claude Code — build log updated automatically after each code change. |
| 11 May 2026 | Full migration from Arduino to ESP-IDF v5.x. All .cpp files replaced with .c. Arduino framework, PubSubClient, ArduinoJson, and Adafruit SSD1306 removed. NimBLE replaces Bluedroid. esp-mqtt replaces PubSubClient. adc_oneshot API replaces legacy ADC. LEDC replaces ledcSetup/ledcWrite. I2C legacy driver with raw SSD1306 init sequence and 5×7 font inline. Motors merged into state_machine.c. Provisioning char upgraded to WRITE+NOTIFY. |
| 12 May 2026 | Android provisioning screen: broker IP auto-detected from phone's WiFi interface. WiFi network filter prevents cellular IP being selected on dual-SIM phones. Broker field is read-only with AUTO-DETECTED badge. |
| 12 May 2026 | HOW_TO_BUILD_AND_FLASH.txt updated: Ubuntu terminal open instructions, erase flash step corrected. |
| 13 May 2026 | BLE redesigned: 30 s re-provision window on every boot. `NVS_KEY_FRESH` flag skips BLE on boot immediately after provisioning. `stop_nimble()` (adv stop → port stop → 300 ms → deinit) called before WiFi init for clean radio handoff. |
| 13 May 2026 | OLED graceful no-hardware handling: `i2c_master_probe()` presence check at init. `s_present` guard in `oled_update()` eliminates 720 ms I2C blocking per loop when no OLED is connected. |
| 14 May 2026 | Android manifest: `FOREGROUND_SERVICE_CONNECTED_DEVICE` permission added — required for Android 14+ foreground service. |
| 14 May 2026 | Android `MainActivity`: fixed 1500 ms startup delay replaced with `MqttBrokerService.isRunning` poll — Paho connects only after Moquette has bound to port 1883. |
| 15 May 2026 | Moquette: `catch (Exception)` → `catch (Throwable)` so Netty startup errors surface in logcat. Root cause: H2 store path defaulting to `/data/` (permission denied). Fixed with `data_path = filesDir.absolutePath`. |
| 15 May 2026 | Android StatusBar: BROKER OK / BROKER DOWN indicator added as live Compose state. |
| 15 May 2026 | End-to-end MQTT verified: ESP32 connects to Moquette on phone, move / mode / speed commands received, telemetry published correctly. |
| 15 May 2026 | Speed control wired end-to-end: `TOPIC_SPEED` subscribed in `mqtt_init()`, `state_machine_set_speed()` added. `run_manual()` uses dynamic `s_speed` (turns use 2/3 of speed). |
| 19 May 2026 | PCBs arrived from JLCPCB. Buck converter circuit assembled (LM2596, diode, inductor, capacitors, trimpot, divider resistors). Output set to 5.0V and verified with multimeter. Battery ADC divider midpoint confirmed at ~4.2V. |
| 22 May 2026 | Remaining components soldered: ESP32, L298N, JST connectors, screw terminals. BLE provisioning functional — minor bugs noted: MQTT status indicator fires too early (shows connected before ESP32 reaches broker), GPIO watchdog trigger on sensor GPIOs. |
| 26 May 2026 | Motor driver tested — both channels functional. Mechanical on/off switch added to the battery line. |
| 28 May 2026 | Manual drive mode fully working. IR sensor data arriving in app correctly. Ultrasonic sensors under investigation (reading 400 cm). |
| 2 Jun 2026 | Motor A direction fixed — IN1/IN2 are wired backwards on the PCB hardware; corrected in `drive()` by inverting PIN_IN1/PIN_IN2 polarity for Motor A only. All move commands now correct. |
| 2 Jun 2026 | AUTO/MAN toggle added to app StatusBar. Sends `line_follow` / `manual` to `robot/control/mode`. D-pad shows overlay and ignores input when AUTO is active. |
| 2 Jun 2026 | WASD fast-tap fix — `collectIsPressedAsState` + `LaunchedEffect` replaced with `pointerInput` + `awaitEachGesture`. Fast taps now correctly send move on press and stop on release. |
| 2 Jun 2026 | Autonomous speed respects MQTT speed — all `m_*` motor helpers (forward, spin, curve, hard-turn) now scale from `s_speed`. Speed slider affects auto mode. |
| 2 Jun 2026 | Battery ADC calibration: `adc_cali_line_fitting` scheme added, 8-sample averaging, fallback uses 3100 mV full-scale (was 3300 mV). App thresholds updated to 6.0V / 5.5V to account for the 6.2V ADC saturation ceiling. |
| 2 Jun 2026 | OLED I2C stability: SCL reduced from 400 kHz to 100 kHz, timeout extended from 10 ms to 50 ms. Error counter: `i2c_master_bus_reset` on 5th consecutive fail, `s_present = false` on 20th (permanently stops updates if OLED disconnects). |
| 2 Jun 2026 | Ultrasonic sensors fixed: polling state machine replaced with interrupt-driven ISR (`GPIO_INTR_ANYEDGE`). Rising edge stores timestamp, falling edge computes `pulse_us / 58` cm. All three sensors now read correctly at all distances. |
| 2 Jun 2026 | ECHO Right confirmed on GPIO2 with ISR. GPIO36/39 were tried and rejected due to ESP32 WiFi/RTC errata causing spurious ISR triggers. Onboard LED flashing with echoes is cosmetic — accepted. |
| 4 Jun 2026 | First line-following calibration session. Test track: electrical tape on floor (~18 mm wide). Robot could detect the line but repeatedly drove off — speed too high for the IR reaction time, correction turns overshot. Speed and turn ratios adjusted iteratively during session. |
| 5 Jun 2026 | Second calibration session. Robot successfully followed a 90-degree curved section of tape at low speed. Motors occasionally failed to start from standstill — stall at low PWM duty; required a physical nudge to break static friction. Minimum startup speed noted as a tuning target. |
| 6 Jun 2026 | Third calibration session. Line following stable enough for consistent laps on the electrical tape track — robot stays on the line through gentle curves without intervention. Motor stall issue reduced by raising the minimum PWM floor. Behaviour considered stable enough for initial validation; further testing needed on a thicker line and sharper turns before calling calibration complete. |

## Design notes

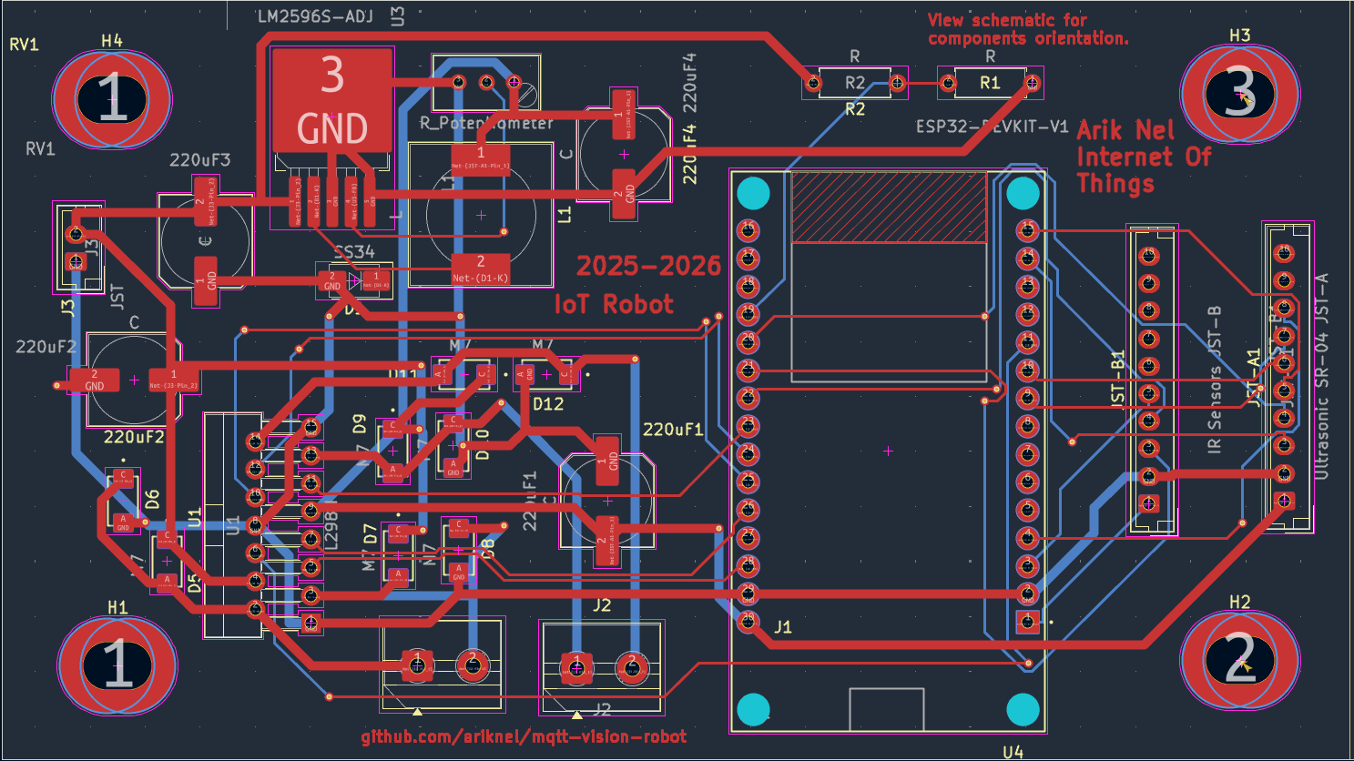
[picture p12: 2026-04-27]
pcb_layout.PNG

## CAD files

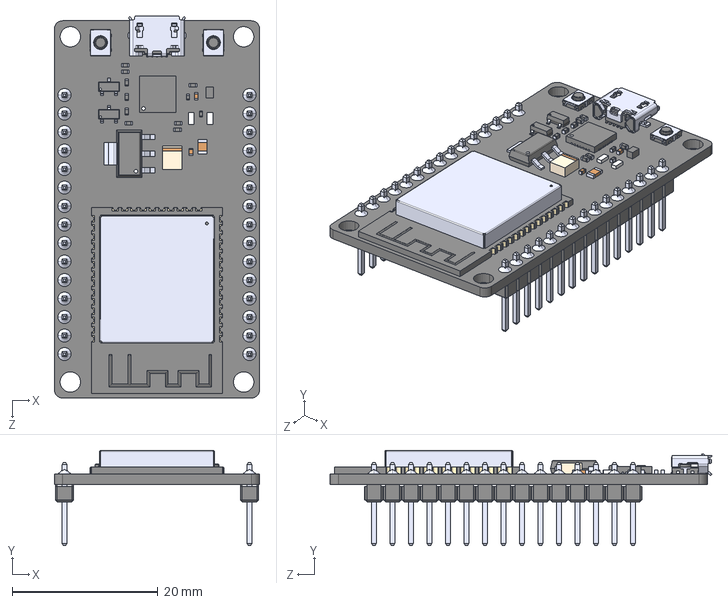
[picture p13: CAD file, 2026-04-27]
footprints/ESP32 Footprint and symbol/ESP32-DEVKIT-V1.step
28.2 x 13.1 x 52.5 mm

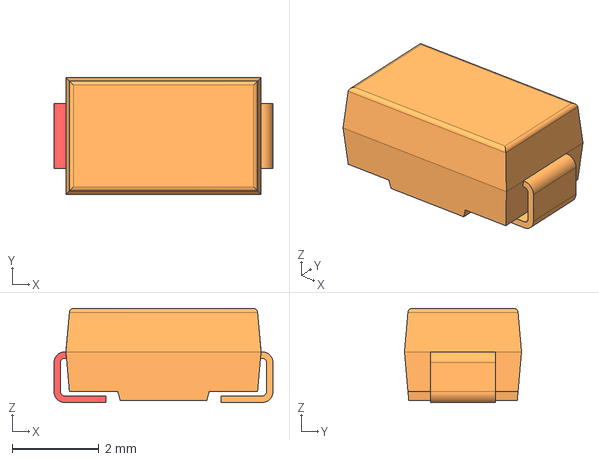
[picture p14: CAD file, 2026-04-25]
footprints/M7/M7.step
5.05 x 2.70 x 2.17 mm

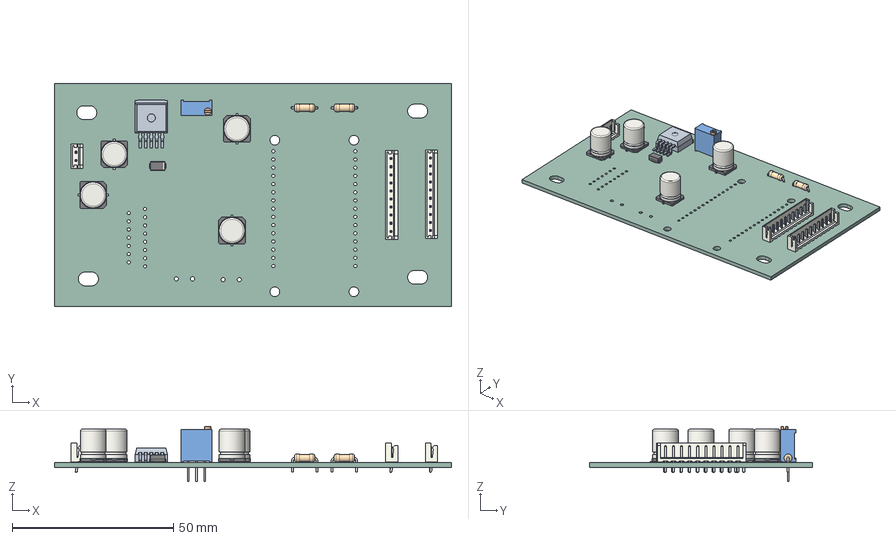
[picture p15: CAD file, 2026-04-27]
mqttvisionrobot.step
123.0 x 69.0 x 17.1 mm
JST_EH_B10B-EH-A_1x10_P2.50mm_Vertical x 2
C_Elec_8x10.2 x 4
D_SMA
Potentiometer_Bourns_3296W_Vertical
.step 1.7.1
R_Axial_DIN0207_L6.3mm_D2.5mm_P7.62mm_Horizontal x 2
JST_EH_B2B-EH-A_1x02_P2.50mm_Vertical
iot_PCB

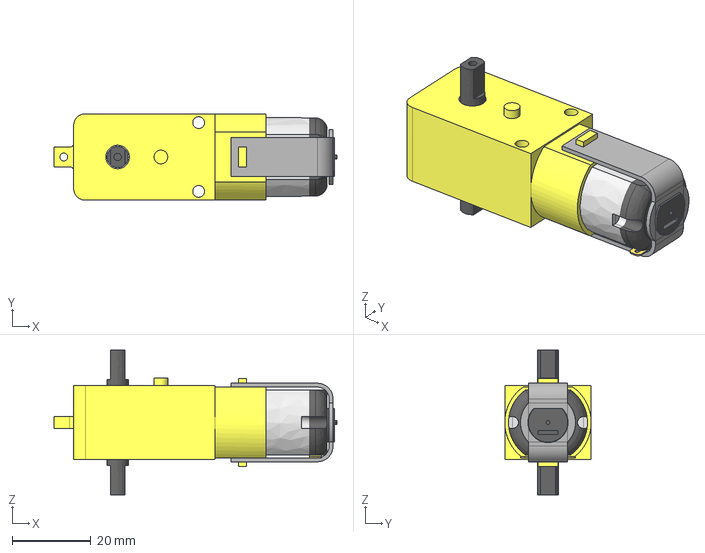
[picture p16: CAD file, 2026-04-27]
toy motor cad/yellow_toy_motor_dims.igs
72.0 x 22.0 x 36.8 mm

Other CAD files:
toy motor cad/yellow_toy_motor_dims.3dm

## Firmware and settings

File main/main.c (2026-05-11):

#include "freertos/FreeRTOS.h"
#include "freertos/task.h"
#include "esp_log.h"

#include "config.h"
#include "provisioning.h"
#include "sensors.h"
#include "state_machine.h"
#include "mqtt.h"
#include "oled.h"

static const char *TAG = "MAIN";

void app_main(void)
{
    ESP_LOGI(TAG, "MQTTVision booting");

    /* Provisioning blocks on first boot until BLE delivers credentials,
     * then restarts. On subsequent boots it loads from NVS and returns. */
    provisioning_init();

    sensors_init();
    state_machine_init();
    mqtt_init();
    oled_init();

    ESP_LOGI(TAG, "All modules ready — entering main loop");

    TickType_t last_telem = xTaskGetTickCount();
    TickType_t last_oled  = xTaskGetTickCount();

    while (1) {
        IRData    ir      = sensors_read_ir();
        UltraData ultra   = sensors_read_ultrasonic();
        float     battery = sensors_read_battery();

        state_machine_update(ir, ultra);

        TickType_t now = xTaskGetTickCount();

        if (now - last_telem >= pdMS_TO_TICKS(TELEMETRY_INTERVAL_MS)) {
            last_telem = now;
            mqtt_publish_telemetry(ir, ultra, battery);
        }

        if (now - last_oled >= pdMS_TO_TICKS(OLED_UPDATE_MS)) {
            last_oled = now;
            oled_update(battery, mqtt_connected(),
                        state_machine_get_mode(), state_machine_get_state());
        }

        vTaskDelay(pdMS_TO_TICKS(MAIN_LOOP_MS));
    }
}

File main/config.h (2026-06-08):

#pragma once

/* MQTT */
#define MQTT_PORT       1883
#define MQTT_CLIENT_ID  "ESP32Robot"

/* MQTT topics */
#define TOPIC_MOVE     "robot/control/move"
#define TOPIC_MODE     "robot/control/mode"
#define TOPIC_SPEED    "robot/control/speed"
#define TOPIC_IR       "robot/telemetry/ir"
#define TOPIC_ULTRA    "robot/telemetry/ultrasonic"
#define TOPIC_BATTERY  "robot/telemetry/battery"

/* Motor pins — L298N */
#define PIN_IN1  13
#define PIN_IN2  14
#define PIN_ENA  21
#define PIN_IN3  27
#define PIN_IN4  26
#define PIN_ENB  25

/* PWM — 1 kHz, 8-bit (0-255) via LEDC */
#define PWM_FREQ  1000

/* IR sensors */
#define PIN_IR_LEFT    32
#define PIN_IR_CENTER  33
#define PIN_IR_RIGHT   15
#define IR_LINE_VALUE      0   /* sensor output when on the line */
#define IR_DEBOUNCE_READS  2

/* Ultrasonic sensors — HC-SR04 (3.3 V echo) */
#define PIN_TRIG_LEFT    22
#define PIN_ECHO_LEFT    35
#define PIN_TRIG_CENTER  23
#define PIN_ECHO_CENTER  19
#define PIN_TRIG_RIGHT   18
#define PIN_ECHO_RIGHT    2  /* GPIO2 — onboard LED flashes with echoes (cosmetic only) */
#define ULTRA_TIMEOUT_US  25000  /* ~4 m max, abort pulse wait after this */

/* Battery ADC — GPIO34 = ADC1_CH6, voltage divider R1=100k R2=100k (1:1).
 * V_pin = Vbat/2.  ADC DB_12 ceiling ~3.1V → saturates above ~6.2V.
 * For 2S this means the reading is fixed at ~6.2V when battery is healthy,
 * and only starts dropping below 6.2V when the pack is critically low. */
#define PIN_BATTERY      34
#define BATTERY_R1       100000.0f
#define BATTERY_R2       100000.0f
#define BATTERY_ADC_MAX    4095.0f

/* OLED — SSD1306 128x32, I2C remapped to GPIO4/5 */
#define PIN_OLED_SDA   4
#define PIN_OLED_SCL   5
#define OLED_ADDRESS   0x3C

/* Speed — 8-bit PWM duty */
#define SPEED_BASE         150  /* default driving speed, overridden by app slider */
#define SPEED_AVOID         90  /* obstacle avoidance — barely moving, cautious */
#define SPEED_CORRECTION    75  /* correction turn speed — gentle, never max RPM */
#define SPEED_POST_CORR     80  /* forward speed when first re-acquiring line */
#define SPEED_RAMP_STEP      2  /* PWM duty added per 10 ms tick while on-line */
#define RECOVERY_CREEP_MS  150  /* creep forward this long after line fully lost before stopping */

/* Obstacle thresholds (cm) */
#define OBSTACLE_WARN_CM  20
#define OBSTACLE_STOP_CM  12

/* State machine timing */
#define RECOVERY_SWEEP_MS   2000
#define RECOVERY_SPIN_MS    5000
#define AVOID_MIN_MS         500
#define POST_AVOID_FWD_MS    600  /* forward creep after obstacle cleared before re-acquiring line */

/* Loop intervals */
#define TELEMETRY_INTERVAL_MS  100
#define OLED_UPDATE_MS         500
#define MAIN_LOOP_MS            10

/* BLE provisioning — re-provision window on every boot (ms) */
#define BLE_PROV_WINDOW_MS  30000

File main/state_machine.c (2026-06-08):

/*
 * state_machine.c — robot autonomy logic + motor control.
 *
 * Motor control lives here (not a separate file) because nothing outside
 * this module drives the motors. Keeping them together removes a layer.
 */
#include "state_machine.h"
#include "config.h"
#include <string.h>
#include <stdbool.h>

#include "driver/gpio.h"
#include "driver/ledc.h"
#include "esp_timer.h"
#include "esp_log.h"

static const char *TAG = "SM";

/* ══════════════════════════════════════════════════════════════
 *  MOTOR CONTROL  (private to this module)
 * ══════════════════════════════════════════════════════════════ */

static void motors_hw_init(void)
{
    gpio_config_t dir = {
        .pin_bit_mask = (1ULL<<PIN_IN1)|(1ULL<<PIN_IN2)|(1ULL<<PIN_IN3)|(1ULL<<PIN_IN4),
        .mode         = GPIO_MODE_OUTPUT,
        .intr_type    = GPIO_INTR_DISABLE,
    };
    gpio_config(&dir);

    ledc_timer_config_t tmr = {
        .speed_mode      = LEDC_LOW_SPEED_MODE,
        .timer_num       = LEDC_TIMER_0,
        .duty_resolution = LEDC_TIMER_8_BIT,
        .freq_hz         = PWM_FREQ,
        .clk_cfg         = LEDC_AUTO_CLK,
    };
    ledc_timer_config(&tmr);

    ledc_channel_config_t ch_a = {
        .gpio_num   = PIN_ENA,
        .speed_mode = LEDC_LOW_SPEED_MODE,
        .channel    = LEDC_CHANNEL_0,
        .timer_sel  = LEDC_TIMER_0,
        .duty = 0, .hpoint = 0,
    };
    ledc_channel_config(&ch_a);

    ledc_channel_config_t ch_b = {
        .gpio_num   = PIN_ENB,
        .speed_mode = LEDC_LOW_SPEED_MODE,
        .channel    = LEDC_CHANNEL_1,
        .timer_sel  = LEDC_TIMER_0,
        .duty = 0, .hpoint = 0,
    };
    ledc_channel_config(&ch_b);
}

/* pwm_a/b: 0-255 duty. fwd_a/b: true = forward, false = reverse. */
static void drive(int pwm_a, bool fwd_a, int pwm_b, bool fwd_b)
{
    gpio_set_level(PIN_IN1, fwd_a ? 0 : 1);
    gpio_set_level(PIN_IN2, fwd_a ? 1 : 0);
    gpio_set_level(PIN_IN3, fwd_b ? 1 : 0);
    gpio_set_level(PIN_IN4, fwd_b ? 0 : 1);
    ledc_set_duty(LEDC_LOW_SPEED_MODE, LEDC_CHANNEL_0, pwm_a);
    ledc_update_duty(LEDC_LOW_SPEED_MODE, LEDC_CHANNEL_0);
    ledc_set_duty(LEDC_LOW_SPEED_MODE, LEDC_CHANNEL_1, pwm_b);
    ledc_update_duty(LEDC_LOW_SPEED_MODE, LEDC_CHANNEL_1);
}

/* ══════════════════════════════════════════════════════════════
 *  STATE MACHINE
 * ══════════════════════════════════════════════════════════════ */

typedef enum { MV_STOP, MV_FORWARD, MV_BACK, MV_LEFT, MV_RIGHT } ManualMove;
typedef enum { AVOID_NONE, AVOID_LEFT, AVOID_RIGHT } AvoidDir;

static RobotMode   s_mode             = MODE_MANUAL;
static RobotState  s_state            = STATE_MANUAL;
static ManualMove  s_move             = MV_STOP;
static int         s_speed            = SPEED_BASE;

static int64_t     s_avoid_clear_us   = 0;
static int64_t     s_post_avoid_us    = 0;
static int         s_fwd_speed        = SPEED_POST_CORR;
static AvoidDir    s_avoid_dir        = AVOID_NONE;

/* Manual driving: all at app-controlled s_speed. */
static void m_stop(void)       { drive(0,       true,  0,       true); }
static void m_forward(void)    { drive(s_speed, true,  s_speed, true); }
static void m_reverse(void)    { drive(s_speed, false, s_speed, false); }
static void m_spin_left(void)  { drive(s_speed, false, s_speed, true); }
static void m_spin_right(void) { drive(s_speed, true,  s_speed, false); }

/* Line corrections: always SPEED_CORRECTION (firm but not violent). */
static void do_pivot_left(void)  { drive(0,               true,  SPEED_CORRECTION, true); }
static void do_pivot_right(void) { drive(SPEED_CORRECTION, true,  0,               true); }
static void do_spin_left(void)   { drive(SPEED_CORRECTION, false, SPEED_CORRECTION, true); }
static void do_spin_right(void)  { drive(SPEED_CORRECTION, true,  SPEED_CORRECTION, false); }

void state_machine_init(void)
{
    motors_hw_init();
    ESP_LOGI(TAG, "State machine ready");
}

/* ── Manual mode: all directions use the same s_speed ─────────────────── */
static void run_manual(void)
{
    switch (s_move) {
        case MV_FORWARD: m_forward();    break;
        case MV_BACK:    m_reverse();    break;
        case MV_LEFT:    m_spin_left();  break;
        case MV_RIGHT:   m_spin_right(); break;
        default:         m_stop();       break;
    }
}

/* ── IR follow: center-gated forward + gradual ramp ─────────────────────
 *
 * Center sensor is the gate for forward motion:
 *   center ON  → robot is over the line → allowed to drive forward (ramp).
 *   center OFF → robot is not over the line → correction only, never forward.
 *
 * This prevents driving into air when picked up, and keeps corrections
 * gentle (SPEED_CORRECTION = 110, never max RPM).
 *
 * All sensors off → enter RECOVERING (brief creep then stop). */
static void run_ir_follow(IRData ir)
{
    int l = (ir.left   == IR_LINE_VALUE);
    int c = (ir.center == IR_LINE_VALUE);
    int r = (ir.right  == IR_LINE_VALUE);

    /* All off: car lifted or fully off track → stop immediately */
    if (!l && !c && !r) {
        s_fwd_speed = SPEED_POST_CORR;
        s_state     = STATE_LIFTED;
        m_stop();
        return;
    }

    /* Center NOT on line: correct without driving forward */
    if (!c) {
        s_fwd_speed = SPEED_POST_CORR;
        if      ( l && !r) do_spin_right();  /* line on left  → spin right to center */
        else if (!l &&  r) do_spin_left();   /* line on right → spin left  to center */
        else               drive(SPEED_POST_CORR, true, SPEED_POST_CORR, true); /* straddle */
        return;
    }

    /* Center on line: check sides for gentle pivot, else roll forward */
    if (l && !r) {
        /* Center + left: slight right drift → gentle pivot right */
        s_fwd_speed = SPEED_POST_CORR;
        do_pivot_right();
    } else if (!l && r) {
        /* Center + right: slight left drift → gentle pivot left */
        s_fwd_speed = SPEED_POST_CORR;
        do_pivot_left();
    } else {
        /* Center only, all three, or straddle: confirmed on line → ramp up */
        if (s_fwd_speed < s_speed) {
            s_fwd_speed += SPEED_RAMP_STEP;
            if (s_fwd_speed > s_speed) s_fwd_speed = s_speed;
        }
        drive(s_fwd_speed, true, s_fwd_speed, true);
    }
}
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

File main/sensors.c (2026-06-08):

#include "sensors.h"
#include "config.h"
#include <string.h>

#include "driver/gpio.h"
#include "esp_adc/adc_oneshot.h"
#include "esp_adc/adc_cali.h"
#include "esp_adc/adc_cali_scheme.h"
#include "esp_timer.h"
#include "esp_rom_sys.h"
#include "esp_log.h"

/* ── IR debounce ──────────────────────────────────────────────────────── */
static int ir_state[3] = {0};
static int ir_prev[3]  = {0};
static int ir_count[3] = {0};

/* ── Ultrasonic — interrupt-driven, one trigger per call ─────────────── */
typedef struct {
    int              trig;
    int              echo;
    volatile int64_t rise_us;   /* rising-edge timestamp, written by ISR */
    volatile int64_t trig_us;   /* when trigger was last fired */
    volatile int     dist_cm;   /* result, written by ISR on falling edge */
    volatile bool    measuring; /* true from trigger until echo complete */
} USSensor;

static USSensor us[3];
static int      us_trig_idx = 0;

static void IRAM_ATTR echo_isr(void *arg)
{
    USSensor *s = (USSensor *)arg;
    int64_t   t = esp_timer_get_time();
    if (gpio_get_level(s->echo)) {
        s->rise_us = t;                          /* rising edge: start timing */
    } else if (s->measuring) {
        int64_t pulse = t - s->rise_us;
        s->dist_cm   = (int)(pulse / 58);        /* falling edge: compute cm  */
        s->measuring = false;
    }
}

/* ── Battery ADC ─────────────────────────────────────────────────────── */
static adc_oneshot_unit_handle_t s_adc;
static adc_cali_handle_t         s_cali = NULL;

static const char *TAG_S = "SENSORS";

/* ─────────────────────────────────────────────────────────────────────── */

void sensors_init(void)
{
    /* IR — inputs, no pull */
    gpio_config_t ir_cfg = {
        .pin_bit_mask = (1ULL<<PIN_IR_LEFT)|(1ULL<<PIN_IR_CENTER)|(1ULL<<PIN_IR_RIGHT),
        .mode         = GPIO_MODE_INPUT,
        .pull_up_en   = GPIO_PULLUP_DISABLE,
        .pull_down_en = GPIO_PULLDOWN_DISABLE,
        .intr_type    = GPIO_INTR_DISABLE,
    };
    gpio_config(&ir_cfg);

    /* Ultrasonic TRIG — outputs */
    gpio_config_t trig_cfg = {
        .pin_bit_mask = (1ULL<<PIN_TRIG_LEFT)|(1ULL<<PIN_TRIG_CENTER)|(1ULL<<PIN_TRIG_RIGHT),
        .mode         = GPIO_MODE_OUTPUT,
        .intr_type    = GPIO_INTR_DISABLE,
    };
    gpio_config(&trig_cfg);

    /* Ultrasonic ECHO — inputs with any-edge interrupt for ISR capture.
     * GPIO35/36 are input-only: no pull-up/down available. */
    gpio_config_t echo_cfg = {
        .pin_bit_mask = (1ULL<<PIN_ECHO_LEFT)|(1ULL<<PIN_ECHO_CENTER)|(1ULL<<PIN_ECHO_RIGHT),
        .mode         = GPIO_MODE_INPUT,
        .pull_up_en   = GPIO_PULLUP_DISABLE,
        .pull_down_en = GPIO_PULLDOWN_DISABLE,
        .intr_type    = GPIO_INTR_ANYEDGE,
    };
    gpio_config(&echo_cfg);

    us[0] = (USSensor){ .trig=PIN_TRIG_LEFT,   .echo=PIN_ECHO_LEFT,   .dist_cm=400 };
    us[1] = (USSensor){ .trig=PIN_TRIG_CENTER, .echo=PIN_ECHO_CENTER, .dist_cm=400 };
    us[2] = (USSensor){ .trig=PIN_TRIG_RIGHT,  .echo=PIN_ECHO_RIGHT,  .dist_cm=400 };

    esp_err_t isr_ret = gpio_install_isr_service(0);
    if (isr_ret != ESP_OK && isr_ret != ESP_ERR_INVALID_STATE) {
        ESP_LOGE(TAG_S, "GPIO ISR service failed (%d)", isr_ret);
    }
    gpio_isr_handler_add(PIN_ECHO_LEFT,   echo_isr, &us[0]);
    gpio_isr_handler_add(PIN_ECHO_CENTER, echo_isr, &us[1]);
    gpio_isr_handler_add(PIN_ECHO_RIGHT,  echo_isr, &us[2]);

    /* ADC — oneshot, 12-bit, 0-3.3 V */
    adc_oneshot_unit_init_cfg_t adc_cfg = { .unit_id = ADC_UNIT_1 };
    adc_oneshot_new_unit(&adc_cfg, &s_adc);

    adc_oneshot_chan_cfg_t ch_cfg = {
        .atten    = ADC_ATTEN_DB_12,
        .bitwidth = ADC_BITWIDTH_12,
    };
    adc_oneshot_config_channel(s_adc, ADC_CHANNEL_6, &ch_cfg); /* GPIO34 */

    /* Calibration — line-fitting is the correct scheme for ESP32.
     * This corrects for the actual ADC full-scale (~3100 mV at DB_12,
     * not 3300 mV) and for per-chip eFuse reference voltage data. */
    adc_cali_line_fitting_config_t cali_cfg = {
        .unit_id  = ADC_UNIT_1,
        .atten    = ADC_ATTEN_DB_12,
        .bitwidth = ADC_BITWIDTH_12,
    };
    esp_err_t ret = adc_cali_create_scheme_line_fitting(&cali_cfg, &s_cali);
    if (ret != ESP_OK) {
        ESP_LOGW(TAG_S, "ADC cali unavailable (err %d) — battery readings will be approximate", ret);
        s_cali = NULL;
    }
}

/* ── IR — debounce: accept reading after IR_DEBOUNCE_READS consistent samples */
IRData sensors_read_ir(void)
{
    const int pins[3] = { PIN_IR_LEFT, PIN_IR_CENTER, PIN_IR_RIGHT };

    for (int i = 0; i < 3; i++) {
        int v = gpio_get_level(pins[i]);
        if (v == ir_prev[i]) {
            if (++ir_count[i] >= IR_DEBOUNCE_READS) {
                ir_state[i] = v;
                ir_count[i] = 0;
            }
        } else {
            ir_prev[i]  = v;
            ir_count[i] = 1;
        }
    }

    return (IRData){ ir_state[0], ir_state[1], ir_state[2] };
}

/* ── Ultrasonic — fire one trigger per call, ISR records the echo time.
 *
 * The old polling design missed echoes from objects <~170 cm because the
 * echo pulse (e.g. 1.8 ms for 30 cm) was already gone by the time the
 * 10 ms loop checked.  The ISR captures the exact rising/falling edges
 * regardless of loop timing.
 */
UltraData sensors_read_ultrasonic(void)
{
    int64_t now = esp_timer_get_time();

    /* Expire any measurement that has been waiting longer than the timeout */
    for (int i = 0; i < 3; i++) {
        if (us[i].measuring && (now - us[i].trig_us) > ULTRA_TIMEOUT_US) {
            us[i].dist_cm  = 400;
            us[i].measuring = false;
        }
    }

    /* Fire the next sensor's trigger only when it is idle */
    USSensor *s = &us[us_trig_idx];
    if (!s->measuring) {
        s->trig_us   = esp_timer_get_time();
        s->measuring = true;
        gpio_set_level(s->trig, 1);
        esp_rom_delay_us(10);
        gpio_set_level(s->trig, 0);
        us_trig_idx = (us_trig_idx + 1) % 3;
    }

    return (UltraData){ us[0].dist_cm, us[1].dist_cm, us[2].dist_cm };
}

/* ── Battery — ADC + voltage divider scaling */
float sensors_read_battery(void)
{
    /* Average 8 samples to reduce RF/switching noise */
    int sum = 0;
    for (int i = 0; i < 8; i++) {
        int r = 0;
        adc_oneshot_read(s_adc, ADC_CHANNEL_6, &r);
        sum += r;
    }
    int raw = sum / 8;

    int mv = 0;
    if (s_cali) {
        adc_cali_raw_to_voltage(s_cali, raw, &mv);
    } else {
        /* Fallback: use 3100 mV (actual DB_12 full-scale), not 3300 mV */
        mv = (int)((float)raw / BATTERY_ADC_MAX * 3100.0f);
    }

    float v_pin = mv / 1000.0f;
    return v_pin * (BATTERY_R1 + BATTERY_R2) / BATTERY_R2;
}

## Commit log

2026-04-25 Added schematic files
2026-04-25 Update README with schematic update notice
    Added a note about schematic updates needed for the 5V input connection.
2026-04-27 Revise README with schematic updates and clarifications
    Updated schematic references and clarified LM2596 connection requirements.
2026-04-27 Fixed ESP32 Headers in pcb schematic
2026-04-27 Added image of pcb 3D
2026-04-27 Document PCB development process in README
    Added detailed PCB development process including schematic design, component placement, board outline, mounting holes, design rules check, auto-routing, and Gerber export steps.
2026-04-27 Change PCB layout image in README
    Updated PCB layout image in README from 'pcb_layout.png' to '3d.png'.
2026-04-27 Added kicad footprints
    [ESP32-DEVKIT-V1.step, M7.step]
2026-04-27 Clarify power source and charger details in README
    Updated power input and battery specifications for clarity.
2026-04-27 Added gerber files used for JLCPCB
    [iot-B_Cu.gbr, iot-B_Mask.gbr, iot-B_Paste.gbr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]
2026-04-27 STEP FILE Voor in assembly inventor
    (robot chassis)
    [iot-F_Silkscreen.step]
2026-04-27 Added cad model for motor
    used inside inventor components assembly
    [yellow_toy_motor_dims.3dm, yellow_toy_motor_dims.igs]
2026-04-29 Updated schematic (VIAS FOR OLED)
2026-05-19 Revise README changelog for recent updates
    Updated changelog with recent project milestones, including migration from Arduino to ESP-IDF v5.x and PCB assembly status.
2026-05-25 Update README with motor driver test results
